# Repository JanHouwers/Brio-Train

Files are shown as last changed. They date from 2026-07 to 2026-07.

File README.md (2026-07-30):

# Brio-Train — a remote-controlled BRIO-compatible locomotive

A 3D-printed, battery-powered locomotive for BRIO-style wooden track, with a matching handheld
remote. Both units use a **Seeed XIAO ESP32-C5** and talk over **ESP-NOW**; both charge over USB-C.

| | Locomotive | Remote |
|---|---|---|
| Controller | XIAO ESP32-C5 | XIAO ESP32-C5 |
| Power | 2S, 2× XTAR 14500 protected (6.0–8.4 V) | 1S, XTAR 26650 protected |
| Charging | IP2326 2S USB-C balance charger | TP4056 USB-C |
| Drive | N20 6 V 150 rpm → DRV8833, O-ring belt to one rear wheel | — |
| Controls | headlight, horn | KY-023 joystick (throttle + horn), link LED, battery LED |
| Link | ESP-NOW broadcast, channel 1, 2.4 GHz, MAGIC-filtered | ESP-NOW, 25 Hz, telemetry ack back |

Speed is roughly 16 cm/s; the firmware caps the PWM duty at 75 % so the 6 V N20 survives the 8.4 V
pack.

> **Build status:** the remote is wired and working. The locomotive is documented and its firmware
> runs on the bare board, but **it is not wired up yet**. The radio link has been demonstrated in
> both directions. See [`docs/status.md`](docs/status.md) for exactly what has and has not been
> tested.

## Repository layout

```
firmware/
  loco/     PlatformIO project — receiver / drive controller  (rev D)
  remote/   PlatformIO project — handheld transmitter          (rev F)
hardware/
  wiring-loco.svg / .png     wiring diagram, locomotive (SVG is the source)
  wiring-remote.svg / .png   wiring diagram, remote
cad/
  Train.3dm / .stp             locomotive body + chassis
  Remote.3dm / .stp            remote enclosure
  pulley-and-wheels.3dm / .stp drive pulley and wheels
stl/
  9 print-ready meshes, generated from the STEP files above
docs/
  bom.md            bill of materials
  wiring-loco.md    wire list L1–L29, measurements, DRV8833 module notes
  wiring-remote.md  wire list W1–W19, battery sensing, deep sleep
  assembly.md       print settings and mechanical assembly
  status.md         build log, what is tested, what is next
```

Only the current revisions are in this repository (loco rev D, remote rev F). Earlier revisions
targeted the XIAO ESP32-S3, which has a different pinout; do not mix them.

## Quick start

### 1. Flash the firmware

Both projects are PlatformIO projects. The ESP32-C5 needs arduino-esp32 core ≥ 3.3, which is not in
the official `espressif32` platform, so both `platformio.ini` files point at the
[pioarduino](https://github.com/pioarduino/platform-espressif32) fork (release 55.03.311). That
requires **PlatformIO Core ≥ 6.1.19**.

```bash
cd firmware/remote        # or firmware/loco
pio run -t upload
pio device monitor -b 115200
```

On Windows, set `PYTHONIOENCODING=utf-8` (or run `chcp 65001`) first — otherwise the upload aborts
halfway with a `UnicodeEncodeError` when esptool draws its progress bar.

No pairing is needed: both ends find each other through a shared `MAGIC` key on Wi-Fi channel 1.

**Flash and bench-test before you solder anything.** With a bare XIAO you can already verify the
radio link, the headlight and the horn.

### 2. Print the parts

Nine parts, ready to slice, in [`stl/`](stl/) — see [`stl/README.md`](stl/README.md) for the part
list and quantities, and [`docs/assembly.md`](docs/assembly.md) for orientation, supports and print
settings. PETG, 0.4 nozzle, 0.2 mm layers, 3 perimeters, 20 % infill.

The STLs are derived from the STEP files in [`cad/`](cad/); the CAD is the source of truth.

### 3. Order the parts

See [`docs/bom.md`](docs/bom.md). Two things in there are easy to get wrong:

- the buck converter must be an **adjustable** MP1584EN set to **5.0 V** (not a fixed Mini-560);
- the master switch in the locomotive carries the full motor current — use one rated **≥ 2 A**, plus
  a 2 A fuse.

### 4. Wire it up

Follow [`docs/wiring-loco.md`](docs/wiring-loco.md) and [`docs/wiring-remote.md`](docs/wiring-remote.md)
alongside the diagrams in [`hardware/`](hardware/). Both documents give the assembly order, the
verification measurements to take before fitting the cells, and the expected values after switching
on. The locomotive has **two separate grounds** (PWR and SIG) joined only through the buck — that is
not a detail, it is what keeps 1 A of motor current out of the ADC reference.

## How it behaves

- Joystick forward/back = speed, press = horn.
- **Neutral lockout**: after power-up or signal loss the locomotive only drives once the stick has
  been at centre.
- **Failsafe**: the locomotive stops 400 ms after signal loss.
- Green LED on the remote = link alive (telemetry ack received from the locomotive).
- Red LED solid = remote cell low; blinking = **locomotive** pack low (the locomotive also stops and
  blinks its headlight).
- The remote deep-sleeps after 5 minutes idle; press the joystick to wake it. It does not sleep while
  a USB host was present at boot, so the COM port stays available while developing.
- Both units print a calibration line over USB every 2 seconds, so the battery measurement can be
  trimmed against a multimeter instead of guessed (`VDIV_CAL`).

## Known limitations

- The throttle scaling is symmetric while the joystick is not, so forward and reverse are not
  perfectly matched. Fix is described in [`docs/wiring-remote.md`](docs/wiring-remote.md).
- There is no breakaway (`MIN_DUTY`) threshold yet, so the first part of the stick travel produces
  whine rather than movement.
- `MAX_DUTY` is a percentage of pack voltage, so speed drops as the pack drains. The locomotive
  already measures the pack, so this can be compensated in firmware.
- Motor speed cannot be measured with the current hardware — no encoder, and the only header ADC pin
  is taken by the pack voltage divider.
- nSLEEP and nFAULT of the DRV8833 are deliberately not wired; protection is entirely in software.

See [`docs/status.md`](docs/status.md) for the full analysis and what is planned next.

## Safety

Lithium-ion cells, a balance charger and a motor driver in a toy: build it carefully.

- The 2S charger must be an IP2326-type **balance** board wired B−/BM/B+. Never charge this pack
  through a plain 1S board.
- Check cell polarity before fitting. The printed bays accept a reversed cell; the protection inside
  the cell will not save the charger.
- The low-battery auto-stop is the primary over-discharge guard — do not disable it.
- Master switch off while charging and while flashing, on both units.
- Body screws on before it goes near a child; charging only under supervision.

## Licence

Firmware is MIT; hardware, CAD and documentation are CERN-OHL-S v2. See [`LICENSE`](LICENSE).

BRIO is a trademark of BRIO AB. This is an independent hobby project, not affiliated with or endorsed
by BRIO.

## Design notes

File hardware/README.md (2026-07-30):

# Wiring diagrams

| Unit | Source | Rendered |
|---|---|---|
| Locomotive, rev D | `wiring-loco.svg` | `wiring-loco.png` (3580 × 2580) |
| Remote, rev F | `wiring-remote.svg` | `wiring-remote.png` (2800 × 2040) |

**The SVG is the source.** The PNGs are rendered from it at 2× scale for viewing and printing; if you
change a diagram, edit the SVG and re-render.

Read them alongside the wire lists — [`../docs/wiring-loco.md`](../docs/wiring-loco.md) and
[`../docs/wiring-remote.md`](../docs/wiring-remote.md) — which carry the wire numbers, gauges,
assembly order and verification measurements.

Conventions used in both diagrams: a filled dot is a connection, a crossing without a dot is not.
In the locomotive diagram a thick line carries motor current (AWG20). Wire numbers (L1…L31, W1…W19)
match the wire lists exactly.

## Re-rendering

**This is automated.** Push a changed SVG and the
[`Render wiring diagrams`](../.github/workflows/render-diagrams.yml) workflow re-renders both PNGs
and commits them back. Pull requests do not get a commit; there the workflow fails if the committed
PNGs no longer match their SVG, so a stale image cannot be merged.

To do it by hand — after editing an SVG locally, or to check the result before pushing:

```powershell
pwsh tools/render-diagrams.ps1
# or, with Windows PowerShell:
powershell -ExecutionPolicy Bypass -File tools\render-diagrams.ps1
```

The script finds Chrome or Edge, reads each SVG's own `width`/`height`, renders at 2× that size and
verifies the resulting image really has those dimensions.

**Render on Windows.** The diagrams specify `Segoe UI, Arial, sans-serif` and were laid out against
Segoe UI metrics; a Linux renderer falls back to a different font and text starts to overflow its
boxes. That is also why the workflow runs on `windows-latest`.

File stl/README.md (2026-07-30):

# Print-ready STLs

Meshed from the STEP files in [`../cad/`](../cad/), which are the Rhino exports of the current
design. Every part is translated to sit on **Z = 0** and centred in X/Y; the orientation is the one
from the CAD.

| File | Qty | Size (mm) | Facets | From |
|---|-----|---|---|---|
| `loco-chassis.stl` | 1 | 130.0 × 34.8 × 35.0 | 4,450 | `Train.stp` → `chassis` |
| `loco-boiler.stl` | 1 | 68.0 × 40.1 × 52.0 | 19,266 | `Train.stp` → `Body` |
| `loco-cab.stl` | 1 | 42.0 × 43.0 × 46.0 | 7,962 | `Train.stp` → `Body001` |
| `loco-front.stl` | 1 | 8.9 × 40.1 × 45.0 | 6,386 | `Train.stp` → `Voorkant` |
| `loco-wheel-plain.stl` | 3 | Ø20.8 × 5.0 | 3,292 | `pulley-and-wheels.stp` → `#1305` |
| `loco-wheel-driven.stl` | 1 | Ø20.0 × 7.6 | 2,584 | `pulley-and-wheels.stp` → `Pulley001` |
| `loco-pulley.stl` | 1 | Ø11.0 × 4.0 | 1,120 | `pulley-and-wheels.stp` → `Pulley` |
| `remote-bottom.stl` | 1 | 170.0 × 56.0 × 22.0 | 6,410 | `Remote.stp` → `Remote bottom` |
| `remote-top.stl` | 1 | 170.0 × 56.0 × 29.2 | 25,984 | `Remote.stp` → `Remote top` |

The locomotive body is split into four printable pieces — chassis, front, boiler and cab — instead of
the single body of earlier revisions. **The split exists to keep support material to a minimum:**
each piece prints in an orientation that needs little or none. The three top pieces (front, boiler,
cab) are **glued together with superglue (cyanoacrylate)**; only the assembled body is screwed to the
chassis.

**Which wheel is which:** `loco-wheel-driven` is the thicker one (7.6 mm, `Pulley001` in the CAD) and
carries the belt hub — it goes on the rear right. `loco-wheel-plain` (5.0 mm) is the running wheel:
twice at the front and once at the rear left.

## Mesh quality

Tessellated at 0.03 mm linear deviation and 0.2 rad angular deviation. All nine meshes are closed
(watertight), have no self-intersections, and their volumes are within 0.32 % of the CAD solids.

## Regenerating

The STLs are derived files — the CAD in [`../cad/`](../cad/) is the source. Export from Rhino, or
regenerate from the STEP files with FreeCAD:

```python
import Import, Mesh, MeshPart
from FreeCAD import Vector
doc = FreeCAD.newDocument("exp")
Import.insert("cad/Train.stp", doc.Name)
obj = doc.getObjectsByLabel("chassis")[0]
sh = obj.Shape.copy()
bb = sh.BoundBox
sh.translate(Vector(-(bb.XMin + bb.XMax) / 2, -(bb.YMin + bb.YMax) / 2, -bb.ZMin))
m = doc.addObject("Mesh::Feature", "m")
m.Mesh = MeshPart.meshFromShape(Shape=sh, LinearDeflection=0.03,
                                AngularDeflection=0.2, Relative=False)
Mesh.export([m], "stl/loco-chassis.stl")
```

See [`../docs/assembly.md`](../docs/assembly.md) for print settings, orientation and supports.

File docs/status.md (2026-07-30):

# Project status — 2026-07-28

Both units run on the **Seeed XIAO ESP32-C5** and were both flashed with the current firmware on
28 July. The remote is wired; the **locomotive is not yet connected** — all documents are ready, but
no wire has been laid. The loco firmware has been seen running on the bare XIAO (the first part of
step 0 below; link LED, buzzer and the PWM test are still open).

The **radio link was demonstrated on 28 July**, in both directions, with both units on USB — see the
link test below.

## Build status — verified 2026-07-28

Both projects were built on the same platform used to flash the remote (`pioarduino 55.03.311`,
arduino-esp32 core 3.3.11, IDF 5.5.5, esptool 5.3.1):

| Project | Result | RAM | Flash |
|---|---|-----|---|
| `firmware/loco` | SUCCESS, 0 warnings | 14.8 % (48,552 / 327,680) | 31.1 % (1,040,695 / 3,342,336) |
| `firmware/remote` | SUCCESS, 0 warnings | 14.8 % (48,592 / 327,680) | 31.1 % (1,037,887 / 3,342,336) |

Nothing comes out with `-Wall -Wextra` either. The two things that break fastest on a C5 —
`esp_wifi_set_band_mode()` and the new `esp_now_register_recv_cb` signature with
`esp_now_recv_info_t` — both compile fine.

## Both units flashed on 28 July — which is which

The two XIAOs can be told apart by their chip MAC. Useful, because they are identical and PlatformIO
will happily flash whichever one you point it at:

| Unit | Chip MAC | Port on 28 July |
|---|---|---|
| **loco** | `10:BD:A3:CF:A7:2C` | COM4 |
| **remote** | `10:BD:A3:CF:09:54` | COM3 |

Check with `pio device list` before every upload which MAC is attached — the port numbers change.
Second check via `device monitor`: the loco prints `pack ... mV ... | link ... armed ... fault ...`,
the remote prints `cell ... mV (... ratio 2.000 ...) | loco ... mV`.

The remote was flashed with `WiFi.setSleep(false)` included; after the reset it runs and reads the
cell at 4023 mV (pin 2011 mV, ratio 2.000). The `loco 8000 mV` in that line is still the startup
value of `locoPackMv` — no locomotive was powered, so no ack had arrived yet.

## Link test loco ↔ remote — passed on 28 July

Both XIAOs on USB simultaneously (COM3 + COM4), both monitors read side by side:

```
REMOTE  cell 4025 mV (...) | loco 7214 mV     LOCO  pack 7285 mV (D0 2428 mV) | link 1 armed 1 fault 0
REMOTE  cell 4025 mV (...) | loco 6735 mV     LOCO  pack 6765 mV (D0 2255 mV) | link 1 armed 1 fault 0
REMOTE  cell 4023 mV (...) | loco 2692 mV     LOCO  pack 3613 mV (D0 1204 mV) | link 1 armed 1 fault 0
REMOTE  cell 4024 mV (...) | loco    0 mV     LOCO  pack   42 mV (D0   14 mV) | link 1 armed 1 fault 0
```

What this proves:

- **Outbound.** `link 1` on the loco: broadcasts arrive that pass the `MAGIC` filter and the length
  check. So channel 1, 2.4 GHz and the `Packet` struct are correct on both sides.
- **Return path.** The remote no longer shows `loco 8000 mV` (the startup value) but a real value,
  and that value **tracks the wobbling D0 reading of the locomotive** — 7214 against 7285, 6735
  against 6765, and both drop to zero. That is not a coincidence: the unicast ack to
  `info->src_addr`, adding the peer, and the `Ack` struct all work. That also means the green link
  LED is lit (`lastAckMs` < 500 ms).
- **`armed 1`.** The locomotive saw `targetSpeed == 0` and released the neutral lockout. Which
  immediately means the joystick zero point at that boot **fell inside the deadband** — the scenario
  in point 1 below (skewed `joyCenter` → never `armed`) did not occur. Note: that is one observation
  at one boot, not a guarantee.

That the pack voltage reads nonsense and wobbles between 0 and 7.3 V is expected: D0 on the
locomotive is still floating. `lowBatt` flips back and forth as a result, and on the remote the red
LED blinks as soon as the reported value drops below 6400 mV.

**Not tested** (impossible without wiring or without extra diagnostics): horn, headlight, and whether
a stick deflection actually produces the right speed — the locomotive does not print `targetSpeed` /
`currentSpeed` anywhere yet.

## Bench test, locomotive — done on 28 July

The bare XIAO was flashed on **COM4** (chip MAC `10:bd:a3:cf:a7:2c`), all four segments with
`Hash of data verified`. The serial monitor shows the calibration line:

```
pack 2643 mV (D0 881 mV, ratio 3.000 x cal 1.000) | link 0 armed 0 fault 0
pack 0 mV (D0 0 mV, ...)      <- wobbles between 0 and 4355 mV
```

That is exactly the expected picture: **D0 is floating and drifts**, so `lowBatt` trips after three
readings and the headlight should blink at 300 ms. `link 0 armed 0` is right too — no remote was
switched on.

That drifting reading is itself the proof it was **the loco XIAO** and not accidentally the remote:
on the wired remote, D0 carries the VRy tap of the joystick, which would give a stable ~1.65 V (pack
would then read a constant ~4950 mV) instead of jumping between 0 and 4355 mV.

**Still to do** from step 0: switch the remote on to check the link LED, press the joystick for the
buzzer, and tie D0 to 3V3 temporarily to release the PWM on D4/D5.

## Two toolchain pitfalls — both solved, but worth remembering

1. **`UnicodeEncodeError` while uploading.** `pio run -t upload` dies with a `charmap` error as soon
   as esptool draws its progress bar: the console is on cp1252 and cannot render those characters.
   The flash is then half finished. Fix: `PYTHONIOENCODING=utf-8` in the environment, or `chcp 65001`
   before the command. This is the same cause as the message *"Firmware metrics can not be shown. Set
   the terminal codepage to utf-8"*.
2. **`build_dir` belongs in `[platformio]`, not in `[env:...]`.** Under the env section PlatformIO
   ignores it without complaining and builds inside the synced folder anyway — and then the build
   fails with `FileNotFoundError` on `.pio`, because the sync client has the directory open. Both
   files are correct now; the warning is included as a comment.

## Locomotive — build order

**Firmware first, wiring second.** Flash the bare XIAO C5 over USB before soldering anything: that
way you test the radio link, the headlight (D9) and the horn (D10) without a single solder joint.

0. **Bench test on the bare XIAO:** *(flashing + calibration line were done on 28 July, the rest not
   yet)*
   ```
   set PYTHONIOENCODING=utf-8
   pio run -t upload
   pio device monitor -b 115200
   ```
   Use PlatformIO Core ≥ 6.1.19 (the `pio` on PATH may be older; the one in
   `%USERPROFILE%\.platformio\penv\Scripts\` is usually current). Without `PYTHONIOENCODING` the
   upload aborts with a `UnicodeEncodeError` — see the pitfalls above.
   - D0 is floating, so the pack voltage reads nonsense and `lowBatt` trips → **the headlight blinks
     at 300 ms**. That confirms that branch works.
   - Switch the remote on: the **green link LED** must come on. That proves the whole radio chain
     (channel 1, 2.4 GHz, MAGIC, Packet/Ack).
   - Press the joystick → the buzzer on D10 must sound.
   - To see the motor drive: tie **D0 to 3V3 temporarily**. The firmware then reads 3.3 × 3.0 = 9.9 V,
     `lowBatt` clears and the PWM on D4/D5 is released.
1. **Measure the DRV8833 module while disconnected**, before anything else: `EEP↔VCC` and `ULT↔VCC`.
   - open or ±47 kΩ → good, carry on
   - near 0 Ω → J1 is closed. **Wick it off first**, otherwise L17 shorts the 3V3 of the XIAO against
     8.4 V as soon as you switch on.
2. **Set the buck to 5.0 V** with a bench supply, before mounting. Adjustable MP1584EN, not a fixed
   Mini-560.
3. **Lay wires L6–L31** (L18–L21 are dropped; that makes 27: L1–L17 + L22–L29 + L30–L31, the
   external USB-C charge socket).
4. **L1–L5** (pack, charger, star point) last, and only then fit the cells.
5. Verification measurements from the wire list — **motor still disconnected**.
6. Reflash, calibrate `VDIV_CAL` against the multimeter on VBAT_SW, and only then connect the motor.
7. Apply throttle with the locomotive on blocks. Free-running N20 = 60–100 mA, stalled 0.7–1 A.

## Protocol check loco ↔ remote — matches

Verified on 28 July, both sides side by side:

| Item | Loco | Remote |
|---|---|---|
| `Packet` | 8 B, `packed`: magic/speed/flags/seq | identical |
| `Ack` | 7 B, `packed`: magic/packMv/seq | identical |
| `MAGIC` | `0xB210C0DE` | identical |
| Channel | 1 | 1 |
| Band | `WIFI_BAND_MODE_2G_ONLY` | `WIFI_BAND_MODE_2G_ONLY` |
| Role | receives broadcast, answers unicast to `info->src_addr` | sends broadcast, receives ack |

## What is deliberately not connected

nSLEEP and nFAULT are **not wired** — the goal is to avoid soldering on the module.

- **EEP** is tied to the 3V3 pin of the XIAO via **L17**. So the driver is always awake (~2 mA idle
  as long as SW1 is on). J1 stays open: VCC is 8.4 V here and the logic pins take 7 V maximum.
- **ULT** stays floating. No detection of short circuit or overheating. That is manageable: the OCP
  of the DRV8833 sits at 2–3.3 A and a stalled N20 only reaches ~1 A, so nFAULT would not have seen
  that anyway.
- **XIAO D1 and D8 stay free.** In firmware: `HAVE_NSLEEP 0` and `HAVE_NFAULT 0`.
- Protection now comes entirely from software: neutral lockout, link timeout, low-battery threshold
  (6600/6900 mV) and `if (!mayDrive) tgt = 0;`. That last line **must stay** — with EEP fixed high,
  `driverAwake` is always true and the ramp counter would otherwise keep running.

## Two things that easily go wrong

- **Two grounds.** PWR = star point at PACK− (pack−, buck IN−, DRV8833 GND, C3/C4). SIG = the GND pin
  of the XIAO (divider, LED1, BZ1). The only connection runs through the buck (L8 ↔ L10). **Do not
  add a second wire between them** — otherwise 1 A of motor current runs through your measurement
  ground.
- **SW1.** The SS12D00 from the original BOM is rated 0.3–0.5 A and has to carry 0.7–1 A here plus
  the inrush of C3. Use a switch rated ≥ 2 A or a P-MOSFET load switch, and a 2 A fuse/PTC directly
  after SW1.

## Next up: diagnostics + joystick ↔ motor speed

None of this is implemented yet — this is the analysis, not the code.

### Where things stand

The radio link is proven (see the link test above), so you can treat it as a given while calibrating.
What is missing is **visibility into the control chain itself**: neither unit prints what the joystick
produces or what the locomotive does with it. As long as that is the case, a locomotive that does not
move is indistinguishable from a locomotive that is being handed a speed of 0. So print first, drive
second.

### The chain stick → speed, and where it can bind

Five links, from the ADC in the remote to the worm gear in the locomotive:

1. **`joyCenter` comes from 32 readings at every boot** (`remote/src/main.cpp`) — and the stick has
   to be released at that moment. If it is not, the zero point is skewed. If it is off by more than
   the deadband, `speed` never becomes 0, the locomotive is **never released** into `armed` and it
   does nothing at all. That looks like a broken radio link while the link is perfectly fine.
   `joyCenter` is not printed anywhere, so right now this is invisible. **First thing to build in.**
2. **The scaling is symmetric, the joystick is not.** `readThrottle()` divides by a fixed 2048,
   regardless of where the centre actually sits. With `joyCenter` = 1900, reverse only reaches 93 %
   and the top 5 % of the forward travel is dead (the constrain clips it). Already listed under
   "still open"; scaling per direction against the real distance to 0 respectively 4095 fixes it.
3. **Deadband ±80 of 1000** = 8 % of the travel. Fine as a rest zone, but it stacks on top of point 4.
4. **There is no breakaway threshold.** A geared N20 only starts moving at roughly 15–25 % duty. The
   region between the deadband and that point therefore produces only current and whine, no movement
   — it feels like a dead zone of a quarter turn. A `MIN_DUTY` where the scale runs from the
   breakaway point to `MAX_DUTY` instead of from 0 makes the stick usable over its whole travel. That
   threshold has to be **measured**, not guessed: on blocks, raise the duty slowly until the wheel
   just turns.
5. **`MAX_DUTY` is a percentage of the pack voltage, not of a fixed motor voltage.** 75 % of 8.4 V is
   6.3 V, but 75 % of 6.6 V (just above the low-battery threshold) is 4.95 V. So the speed at the
   same stick position drops ~21 % as the pack drains. The locomotive **already measures `packMv`**,
   so compensating costs no extra wire: derive the duty from a desired motor voltage. Watch the upper
   limit — never above 80 % duty, and with a full pack never above the 6.3 V the N20 is set up for.

### Hard limitation: speed cannot be measured with the current hardware

There is **no encoder on the N20**, and back-EMF measurement is not possible here: of the header pins
only **D0 (GPIO1) is on ADC1**, and it is taken by the pack voltage divider. The C5 has no ADC2. So
"speed" is by definition a derivative of duty and motor voltage, supplemented by what you determine
on blocks by eye or with a tacho app. Measuring it properly is a **hardware change** — an optical or
hall sensor on a free GPIO (D1 and D8 are free, see `HAVE_NSLEEP 0` / `HAVE_NFAULT 0`) — and then the
pin assignment has to go past the wire list again.

### What could be built in

**Remote:**
- Extend the calibration line with the raw ADC value, `joyCenter`, and `v` after scaling. Without
  those three, calibrating is guesswork.
- Calibration mode: hold the joystick pressed at boot → measure the end stops and centre and write
  them to NVS (`Preferences`), so the zero point no longer depends on whether the stick happened to
  be released at boot.
- Scale per direction (point 2).

**Locomotive:**
- Extend the calibration line with `targetSpeed`, `currentSpeed` and the actual duty, plus
  `armed`/`mayDrive`/`lowBatt`/`faultShutdown` as separate flags. Right now you only see
  `link armed fault`.
- `MIN_DUTY` and voltage compensation (points 4 and 5), only after the breakaway point is measured.

**Telemetry — mind the trap:** extending the `Ack` with speed and status flags is the clean way to
see on the remote what the locomotive is doing, but **both sides filter on `len != sizeof(...)`**. If
you change the struct, loco and remote must be reflashed in the same pass, otherwise the link goes
silent without any message — the packets are simply discarded.

## Still open, apart from the locomotive

- **Headlight LED, 47 Ω.** With a white LED (Vf ≈ 3.0–3.2 V) only 0.1–0.3 V is left across the
  resistor; the LED itself becomes the limiter and the brightness is not well defined. Put a red LED
  in there by mistake and you draw ~30 mA from the GPIO. More robust: drive the headlight from the
  5 V rail through an NPN (BC547, 1 kΩ base resistor from D9) with **180 Ω** in series.
- **Green LED on the remote, 470 Ω.** 470 Ω is right for the red LED (Vf ≈ 1.9 V → 3 mA), but a
  bright green InGaN LED has Vf ≈ 3.0–3.2 V and barely lights up. Use a green one with Vf ≤ 2.2 V, or
  220 Ω.
- `readThrottle()` in the remote firmware scales both directions equally; with a joystick whose
  centre is not exactly at half, forward and reverse are not symmetric. The fix (scale per direction)
  has been discussed but is not in the code yet.
- **The locomotive enclosure has not been test-fitted against the wired electronics.** The CAD in
  [`../cad/`](../cad/) is the current source and print-ready meshes are in [`../stl/`](../stl/). The
  body is split into a chassis plus three top pieces (front, boiler, cab) so each prints with little
  or no support; the three top pieces are glued together with superglue. The e-shelf tray from the
  earlier design is gone — the boards mount in the chassis and the space inside the boiler and cab
  takes the rest, so every board has to be insulated (Kapton) with no exposed conductors before it
  goes in. Charging runs through a separate 2-wire USB-C socket (L30/L31) instead of the charger
  board's own port.

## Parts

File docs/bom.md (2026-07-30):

# Bill of Materials

Current hardware revision: **loco rev D / remote rev F**, both on the Seeed **XIAO ESP32-C5**.
Component designators (R1, C3, SW1, …) match [`wiring-loco.md`](wiring-loco.md) and
[`wiring-remote.md`](wiring-remote.md) and the two wiring diagrams in [`../hardware/`](../hardware/).

> Earlier revisions of this project used the XIAO ESP32-S3. The C5 has a different pinout and only
> one ADC unit; do not mix the two. See the wire lists for the details.

## Controllers and cells

| # | Part | Notes |
|---|---|---|
| 2 | Seeed XIAO ESP32-C5 | 1× loco, 1× remote (21 × 17.5 mm). Requires arduino-esp32 core ≥ 3.3 |
| 2 | XTAR 14500, 3.7 V 1200 mAh, protected | Ø14.3 × 50.5 mm — loco pack, 2S (6.0–8.4 V) |
| 1 | XTAR 26650, 3.6 V 6000 mAh, protected, button top | Ø26.5 × 69.3 mm — remote, 1S |

Protected 14500 cells are 50.5 mm — 0.5 mm longer than an AA. The printed bay accounts for this; an
off-the-shelf AA holder may be too tight.

## Locomotive

| # | Ref | Part | Spec / example | Why |
|---|-----|---|---|-----|
| 1 | M1 | N20 gearmotor | 6 V, ~150 rpm, metal gears, 3 mm D-shaft, body 12 × 10 × 24 mm | Drive. 2 A protected cells handle N20 stall (~0.7–1 A) fine |
| 1 | U4 | DRV8833 module | Dual H-bridge breakout, ~18 × 15 mm, Vmax 10.8 V | Motor driver, runs directly off the 2S pack. One channel used |
| 1 | U1 | 2S USB-C Li-ion charge module | IP2326-based, "2S 8.4 V USB-C balance charging board" | Built-in USB-C charging including balancing of both cells |
| 1 | J2 | USB-C female connector, 2-wire, with snap-groove buckle | 3 A "fast charge" type, e.g. Greluma 5-pack (amazon.nl) | Charge socket. Its two leads solder to the charge input of U1, so the USB-C port of the charger board itself does not have to reach a wall |
| 1 | U2 | Buck converter, **adjustable** | MP1584EN set to **5.0 V**, ≥1 A | 2S pack → 5V pin of the XIAO. **Not** a fixed Mini-560 — see below |
| 4 | — | AA battery contacts | 2× spring (negative) + 2× button plate (positive), Keystone 5201/5203 style or from a scrap AA holder | Press into the printed battery bay |
| 1 | SW1 | Slide switch, **≥ 2 A** | 1P2T, 3–4 mm travel | Master power. The SS12D00 from earlier revisions is too light — see below |
| 1 | — | Fuse or PTC, 2 A | — | Directly after SW1 |
| 1 | LED1 + R1 | White LED 5 mm + 47 Ω | LED with Vf ≤ 2.9 V | Headlight |
| 1 | BZ1 + R2 | Passive piezo buzzer + 100 Ω | 12 mm disc or 9 mm passive buzzer | Horn |
| 2 | — | O-ring | 18 × 2 mm NBR | 1× tyre on the driven wheel, 1× drive belt motor→wheel |
| 1 | — | Steel rod | Ø3 × 32 mm | Front axle (press-fit wheels, spins in the chassis) |
| 2 | — | M3 × 12 screw + washer | — | Rear stub axles; both rear wheels free-spin, the right one is belt-driven |
| 2 | — | Neodymium disc magnet | Ø10 × 3 mm | Couplers front and rear. Check polarity against a Brio wagon before gluing |
| 1 | R3 | Resistor 200 kΩ | 1 % | Pack voltage divider, top leg |
| 1 | R4 | Resistor 100 kΩ | 1 % | Pack voltage divider, bottom leg (ratio 3.0 → D0) |
| 1 | C1 | 100 nF ceramic, X7R | — | Across the divider tap to SIG ground. The divider is 67 kΩ source impedance; the SAR ADC wants < 10 kΩ |
| 1 | C3 | 100 µF low-ESR electrolytic, ≥ 16 V | — | HF decoupling of the H-bridge, loop < 2 cm |
| 1 | C4 | 100 nF ceramic | — | In parallel with C3 |
| 1 | C5 | 10 nF ceramic | — | Across the motor terminals. Do not go larger: 100 nF burns 0.14 W at 20 kHz PWM |
| — | — | Wire | AWG20 (power/motor), AWG22, AWG24, AWG26 (signals) | See the wire list for which gauge goes where |
| — | — | Heat-shrink | — | — |
| — | — | Kapton (polyimide) tape | 10–20 mm wide | Insulate every board before fitting. Everything ends up packed together inside the chassis and body |

## Remote

| # | Ref | Part | Spec / example | Why |
|---|-----|---|---|-----|
| 1 | U1 | TP4056 USB-C charge module | With protection (DW01+FS8205), 1 A | Built-in USB-C charging of the 26650 (~7 h full charge) |
| 1 | J1 | Joystick module | KY-023 dual axis with push switch, 34 × 26 mm | Throttle (Y axis) fwd/rev, push = horn |
| 1 | SW1 | Slide switch | SS12D00 (fine here — no motor current) | Master power |
| 1 | LED1 + R1 | Green LED 3 mm + 470 Ω | **Vf ≤ 2.2 V**, otherwise use R1 = 220 Ω | Link status |
| 1 | LED2 + R2 | Red LED 3 mm + 470 Ω | — | Low battery |
| 1 | R5 | Resistor 100 kΩ | — | External pull-up on D1 (JOY_SW). The internal pull-up disappears in deep sleep |
| 1 | C2 | 100 µF low-ESR electrolytic (≥ 6.3 V) | — | ESP-NOW draws 250–350 mA peaks; without it a nearly empty cell browns the XIAO out |
| 1 | C3 | 100 nF ceramic | — | In parallel with C2 |
| 4 | — | Screws M3 × 12 self-tapping | — | Enclosure halves |
| 2 | — | Battery contacts | 26650/C-cell spring + plate, or solder tabs | Printed battery bay |
| 1 | — | Foam pad 1–2 mm | EVA or double-sided foam tape, ~10 × 10 mm | Between the top-shell pillar and the XIAO RF shield (clamps the board) |

**Dropped compared to the S3 revision:** the external battery divider (R3, R4) and its filter cap
(C1), plus wires W5, W8 and W9. On the C5 the battery sense runs through the divider on the XIAO
itself (GPIO6, enabled by GPIO26), which is not reachable from the header.

## Component notes

- **Do not run the N20 at the full 8.4 V** — the firmware caps PWM duty at 75 % (≈6.3 V effective).
  This is by design; do not raise `MAX_DUTY` above 80.
- **The buck must be adjustable and set to 5.0 V.** The 5V pin of the XIAO feeds the on-board
  SGM40567, which wants to see ~4.5–5.5 V. A fixed Mini-560 no longer reaches 5 V below about 6.5 V
  input, and that is *above* the low-battery stop; the MP1584EN holds 5.0 V down to about 5.4 V in.
- **SW1 in the locomotive carries the full motor current** (0.7–1 A stalled) plus the inrush of C3.
  The SS12D00 is rated 0.3–0.5 A — use a switch rated ≥ 2 A, or have SW1 drive a P-MOSFET load
  switch. Add a 2 A fuse directly after it.
- **The 2S charge module charges through the balance tap (B−, BM, B+).** The midpoint (BM) is the
  junction between the two 14500 cells — it must be wired even though the cells are individually
  protected. Never charge this pack through a plain 1S board.
- **The XIAO in the remote is powered from its BAT pads** (cell voltage). Its own USB port then also
  trickle-charges the cell at ~100 mA if plugged in — harmless, but the TP4056 USB-C port is the
  intended charge port, and with USB plugged in the battery reading always says "full".
- **Headlight LED, 47 Ω:** with a white LED (Vf ≈ 3.0–3.2 V) only 0.1–0.3 V is left across the
  resistor; the LED itself becomes the limiter and brightness is not well defined. Put a red LED
  there by mistake and you draw ~30 mA from the GPIO. More robust: drive the headlight from the 5 V
  rail through an NPN (BC547, 1 kΩ base resistor from D9) with **180 Ω** in series.
- **Green link LED, 470 Ω:** correct for a red LED (Vf ≈ 1.9 V → 3 mA), but a bright green InGaN LED
  has Vf ≈ 3.0–3.2 V and barely lights up. Use a green LED with Vf ≤ 2.2 V, or 220 Ω.

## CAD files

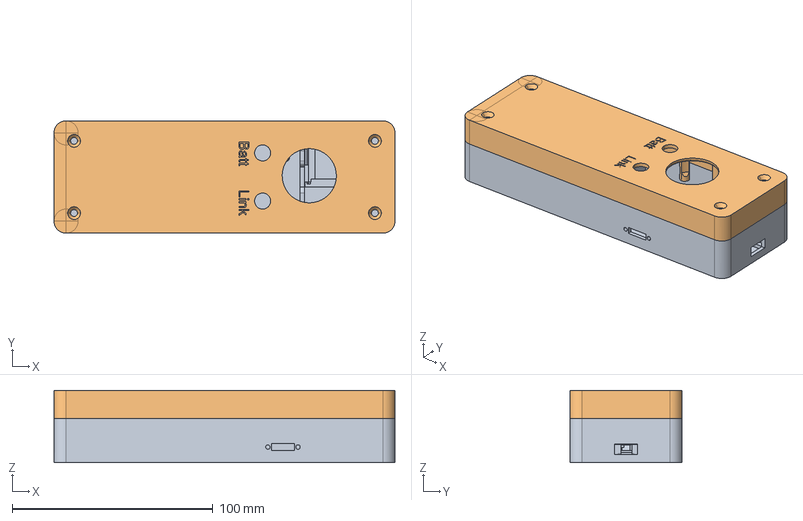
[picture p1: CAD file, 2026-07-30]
cad/Remote.stp
170.0 x 56.0 x 36.0 mm
Remote bottom
Remote top

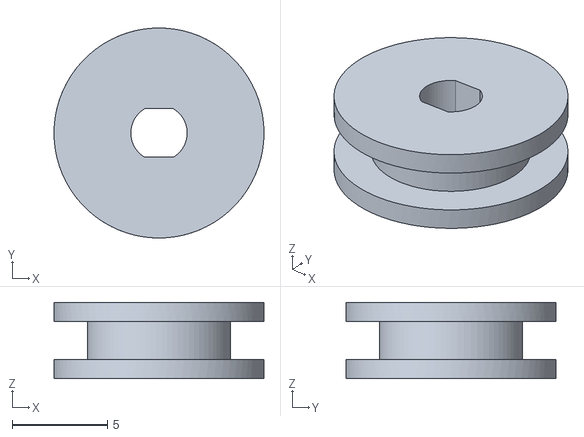
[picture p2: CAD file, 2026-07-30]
stl/loco-pulley.stl
11.0 x 11.0 x 4.00

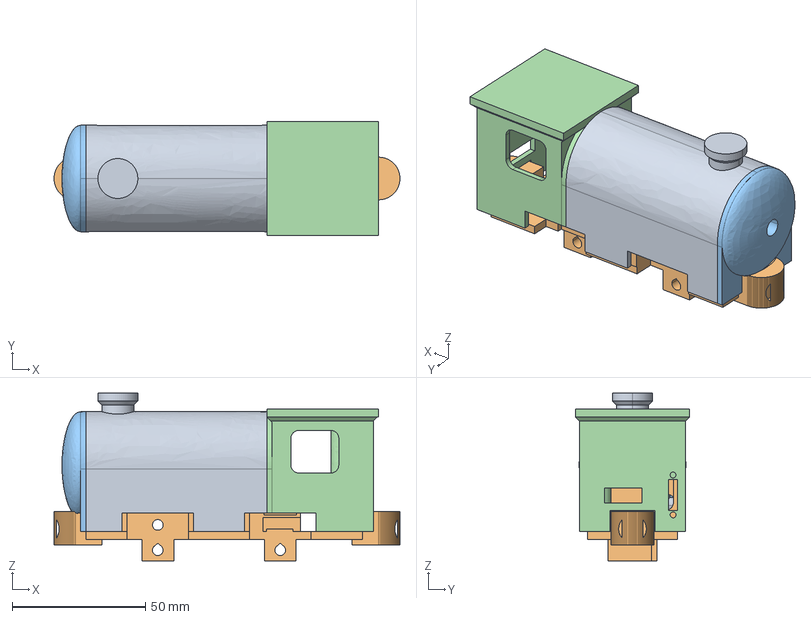
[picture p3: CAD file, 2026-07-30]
cad/Train.stp
130.0 x 43.0 x 63.0 mm
chassis
Voorkant

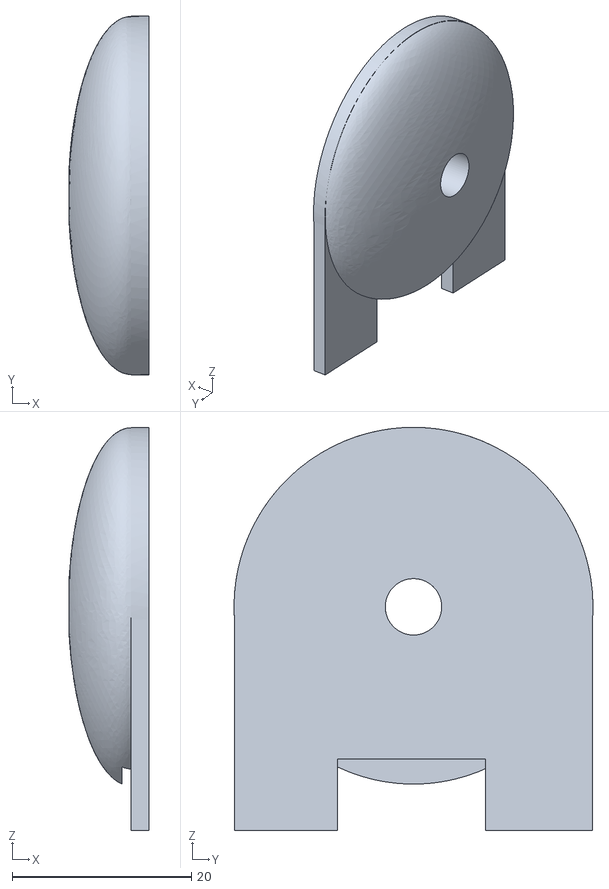
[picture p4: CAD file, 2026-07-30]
stl/loco-front.stl
8.91 x 40.1 x 45.0

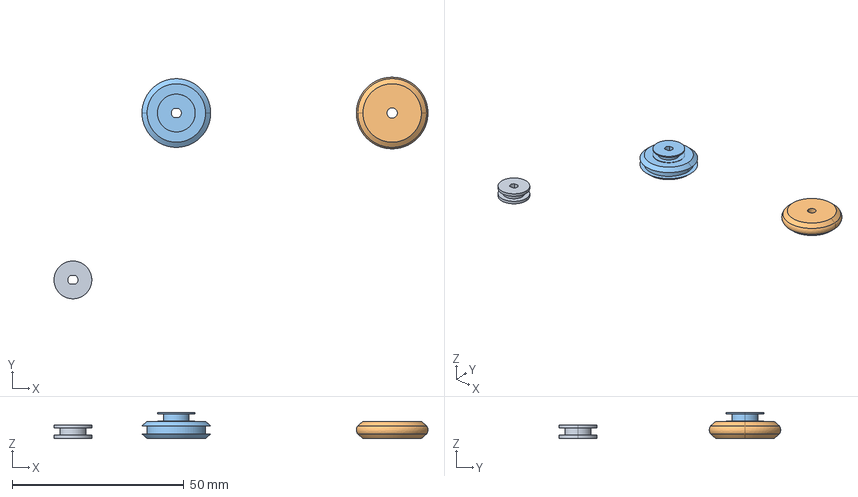
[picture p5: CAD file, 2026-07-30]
cad/pulley-and-wheels.stp
108.8 x 64.5 x 7.57 mm
Pulley x 2

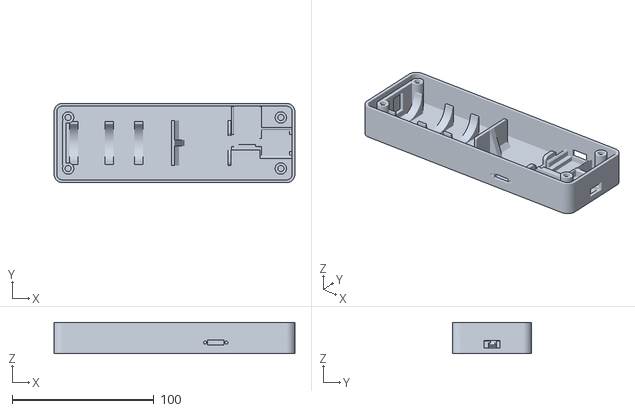
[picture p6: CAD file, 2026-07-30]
stl/remote-bottom.stl
170.0 x 56.0 x 22.0

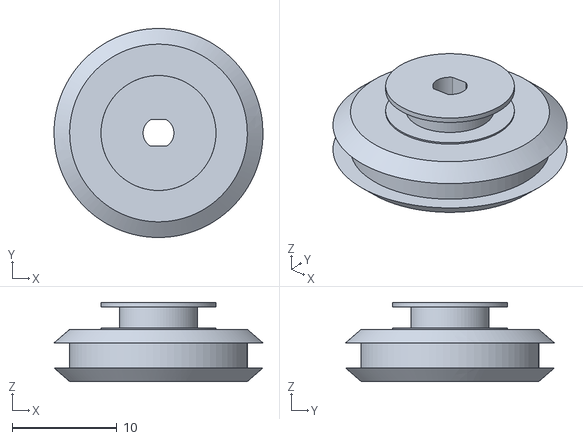
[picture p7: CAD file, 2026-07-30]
stl/loco-wheel-driven.stl
20.0 x 20.0 x 7.57

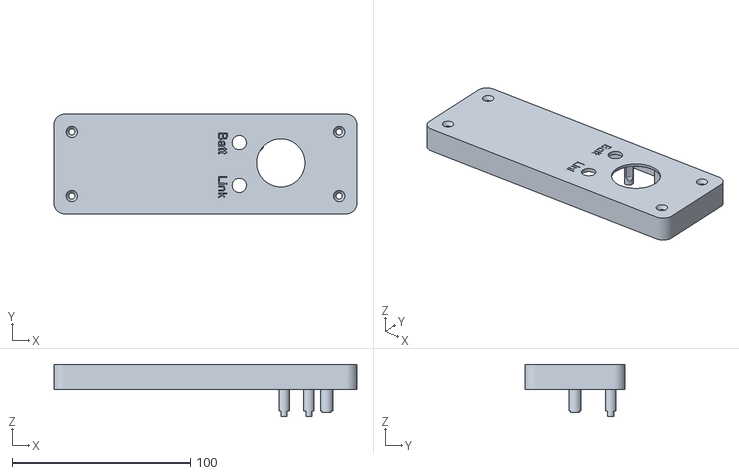
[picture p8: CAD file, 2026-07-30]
stl/remote-top.stl
170.0 x 56.0 x 29.2

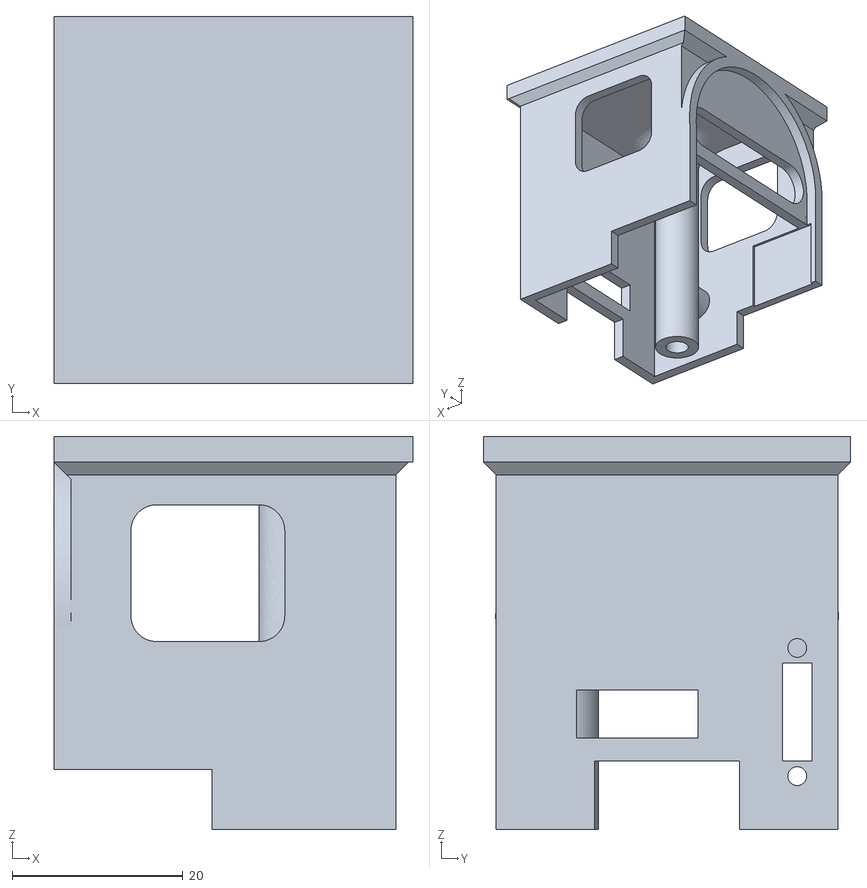
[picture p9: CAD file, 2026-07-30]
stl/loco-cab.stl
42.0 x 43.0 x 46.0

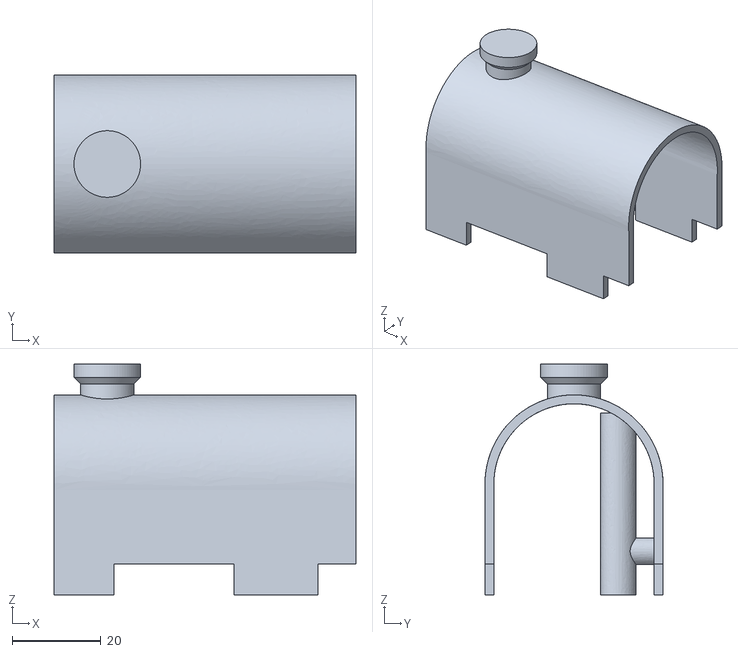
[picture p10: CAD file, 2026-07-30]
stl/loco-boiler.stl
68.0 x 40.1 x 52.0

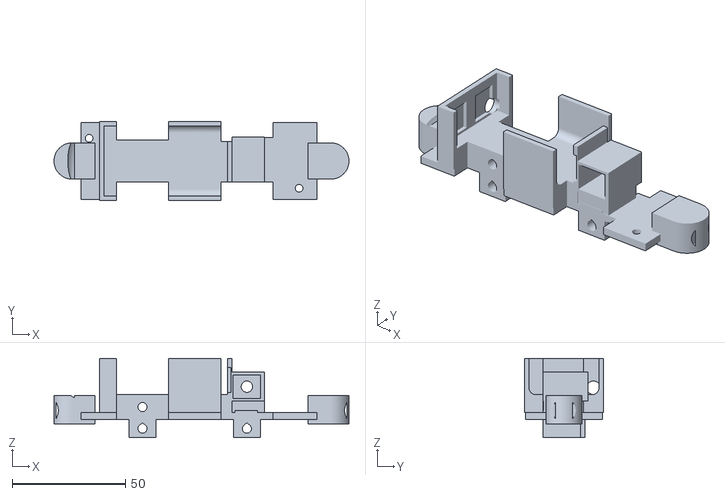
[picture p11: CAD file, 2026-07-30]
stl/loco-chassis.stl
130.0 x 34.8 x 35.0

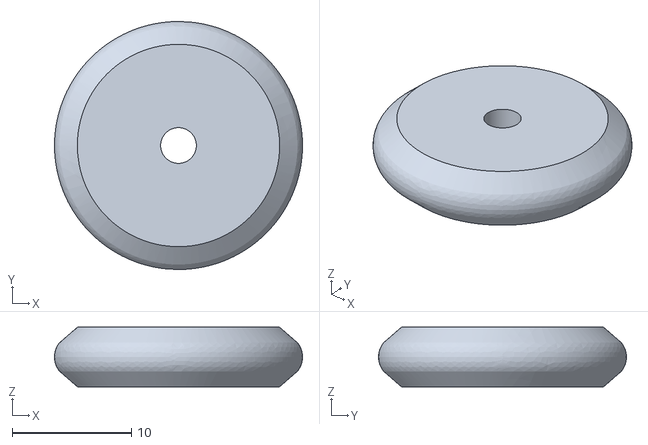
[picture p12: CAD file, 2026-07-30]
stl/loco-wheel-plain.stl
20.8 x 20.8 x 5.00

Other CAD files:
cad/Remote.3dm
cad/Train.3dm
cad/pulley-and-wheels.3dm

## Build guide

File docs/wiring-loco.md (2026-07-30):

# Locomotive — wire list rev D (XIAO ESP32-**C5**)

Goes with [`hardware/wiring-loco.svg`](../hardware/wiring-loco.svg) and
[`firmware/loco/src/main.cpp`](../firmware/loco/src/main.cpp) (PlatformIO). Successor to rev C,
which was for the ESP32-S3. **The wiring itself has not changed** — L1 through L29 still run to the
same components. What changed is **which XIAO label** each signal sits behind, plus the buck
setting.

> Both ends now run on a C5. The remote is documented in [`wiring-remote.md`](wiring-remote.md).

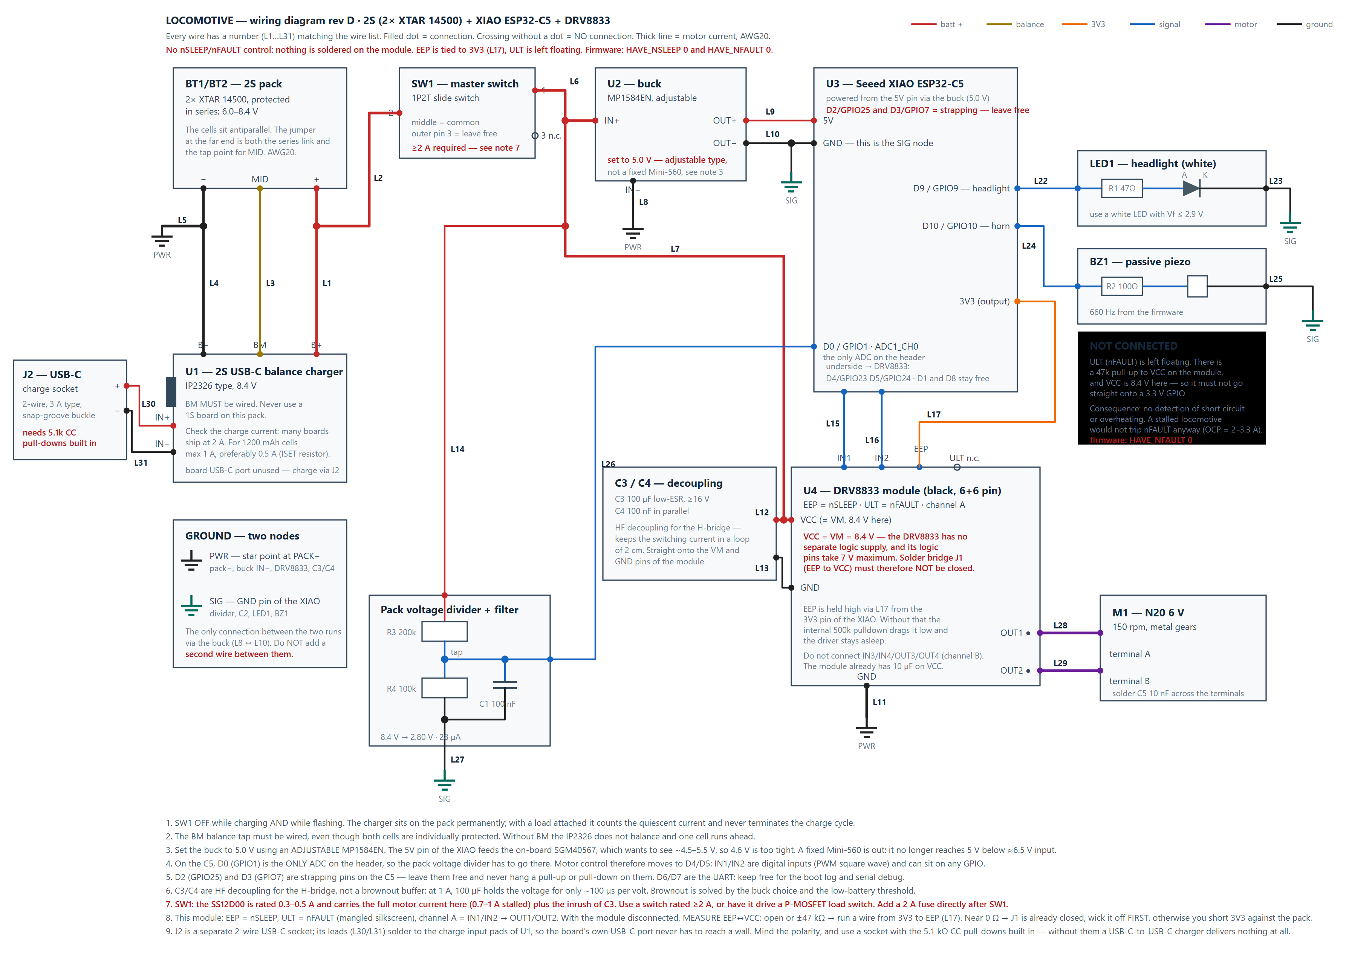
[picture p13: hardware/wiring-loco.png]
Locomotive wiring diagram rev D


## Read this first — four ways to get it wrong

1. **The DRV8833 module used here (black, 6+6 pins) has J1 and a 47k pull-up to VCC.** And on this
   board "VCC" is simply VM, so **8.4 V** — the DRV8833 has no separate logic supply. Connect EEP or
   ULT without removing those and you put 8.4 V on a 3.3 V GPIO. See the separate section
   **"Your module"** below; that is the first thing to check.
2. **The slide switch from the BOM is too light.** The SS12D00 is rated 0.3–0.5 A; the full motor
   current runs through it here (0.7–1 A stalled) plus the inrush of C3. Use ≥2 A, or have SW1 drive
   a P-MOSFET load switch. Plus a 2 A fuse directly after it.
3. **The buck must be set to 5.0 V, and it must be an adjustable type.** See below — this changed
   compared to rev C.
4. **The cell bay is antiparallel.** Nothing stops a reversed cell. Mark the polarity and measure
   PACK+ ≈ 2× MID before switching on for the first time.

## Your module — read this before connecting anything

The silkscreen on this board is mangled English. Decoded:

| Silkscreen | Means | In this design |
|---|---|---|
| `IN1` `IN2` | AIN1, AIN2 | channel A, from D4 and D5 |
| `IN3` `IN4` | BIN1, BIN2 | channel B — **do not connect** |
| `OUT1` `OUT2` | AOUT1, AOUT2 | to the motor |
| `OUT3` `OUT4` | BOUT1, BOUT2 | **do not connect** |
| `EEP` | n**SLEEP** | from D1 |
| `ULT` | nFA**ULT** | to D8 |
| `VCC` | **VM** — there is no separate logic supply | 8.4 V |
| `GND` | ground | PWR star point |
| `J1` | solder bridge next to EEP, silkscreen "en sleep" | connects EEP to VCC |

**That VCC is the same net as VM is the whole problem.** The DRV8833 has one supply pin. Everything
on this board tied to VCC therefore sits at pack voltage, not 3.3 V. On the front there is a `473`
(47 kΩ) and a `472` (4.7 kΩ); the 4.7k belongs to the green LED, the 47k is almost certainly the
pull-up on ULT.

### Measuring (module disconnected, nothing hooked up)

| Measurement | Result | What you do |
|---|---|---|
| **EEP ↔ VCC** | open or ± 47 kΩ | wire from XIAO **3V3** to EEP — done |
| | near 0 Ω | J1 is closed: wick it off first, only then connect 3V3 |
| **ULT ↔ VCC** | does not matter | ULT stays floating |

### Chosen approach: do not desolder

`src/main.cpp` is therefore set to:

```c
#define HAVE_NSLEEP  0    // 1 = EEP on D1, only after J1 is removed
#define HAVE_NFAULT  0    // 1 = ULT on D8, only after the 47k is removed
```

**Leave ULT floating.** There is nothing else to do.

**EEP does have to be held high** — otherwise the internal 500 kΩ pulldown drags it low and the
driver stays asleep; the motor will never move.

> **Do not use J1 for this.** It connects EEP to VCC, and VCC on this board is VM: 8.4 V with a full
> pack. The logic pins of the DRV8833 — including nSLEEP — have an **absolute maximum of 7 V**
> (TI datasheet). Closing J1 therefore puts 1.4 V too much on it, precisely when the pack is full.

**Instead, run a single wire from the 3V3 pin of the XIAO to EEP.** That is L17 in the wire list,
only from 3V3 instead of from D1. nSLEEP then sits at 3.3 V, well within spec, the driver is
permanently enabled, and you do not have to solder anything on the module.

First measure **EEP ↔ VCC** with the module disconnected:

- **open, or ± 47 kΩ** → wire from 3V3 to EEP. Done. (With a 47k to VCC, 108 µA flows into the 3V3
  rail — negligible.)
- **near 0 Ω** → J1 was closed at the factory. Do **not** connect 3V3, because that would short the
  XIAO 3V3 rail against the pack. Wick the bridge off first — removing a solder bridge is a lot
  easier than removing an 0603 — and then run the wire to 3V3.

At boot this is safe: EEP goes high as soon as 3V3 is present, but IN1/IN2 are still high-Z at that
point and the DRV8833 has internal pulldowns on them. Both low = coast.

What this approach costs you:

- **without nSLEEP**: the driver is always on (~2 mA idle as long as SW1 is on) and you cannot clear
  a fault latch. The failsafe still works: on signal loss the firmware drives both inputs low and the
  locomotive coasts to a stop.
- **without nFAULT**: you do not see short circuits or overheating. That is less bad than it sounds —
  see the note at the bottom about what nFAULT does and does not catch.

The module already has **10 µF** on VCC (the orange block marked `106C`). C3/C4 are still worth it:
10 µF is little for the peak current of an N20.

The green LED on the module hangs off VCC through 4.7 kΩ and therefore burns continuously as long as
SW1 is on — about 1.4 mA out of your pack. If you do not want that, remove the 4.7 kΩ.

## Why the pins differ from the S3

The ESP32-C5 has exactly **one ADC unit**: ADC1, six channels, on GPIO1 through GPIO6. There is no
ADC2 — the Wi-Fi/ADC2 conflict of the S3 does not exist on this board. But of the **header pins** of
the XIAO C5, only **D0 (GPIO1)** is on that ADC. So the pack voltage divider has to go there.

That the motor control moves as a result is no problem: **AIN1 and AIN2 of the DRV8833 are digital
inputs.** Speed is the duty cycle of a 20 kHz square wave from the LEDC hardware, not an analog
voltage. The same holds for nSLEEP (output) and nFAULT (open-drain input). So the DRV8833 needs zero
ADC pins; the pack voltage is the only analog measurement in the whole locomotive.

**Two header pins stay empty.** Strapping pins on the C5 are GPIO2, GPIO7, GPIO25, GPIO27 and
GPIO28. On the header those are **D3 (GPIO7)** and **D2 (GPIO25)**. A strapping pin must have no
external pull-up or pulldown at reset — the chip reads that level as a boot option. That is why D2
and D3 stay unwired. In this build **D1 and D8 also stay free**: those were nSLEEP and nFAULT, and
they are not connected.

**D6 and D7 (GPIO11/GPIO12) are the UART.** Keep them free: that is where the boot log comes out and
where you hang a USB-TTL adapter when USB-CDC lets you down.

## Pinout, C5 versus S3

| Label | Net | S3 (rev C) | C5 (rev D) | Note |
|---|-----|---|---|---|
| D0 | VSENSE | GPIO1 = AIN1 | **GPIO1** | ADC1_CH0 — the only ADC on the header |
| D1 | ~~nSLEEP~~ | GPIO2 = AIN2 | **GPIO0** | **free** — nSLEEP is not driven |
| D2 | — | GPIO3 = headlight | **GPIO25** | **strapping — leave free** |
| D3 | — | GPIO4 = horn | **GPIO7** | **strapping — leave free** |
| D4 | AIN1 | GPIO5 = VSENSE | **GPIO23** | ordinary GPIO, PWM through the GPIO matrix |
| D5 | AIN2 | GPIO6 = nSLEEP | **GPIO24** | idem |
| D6/D7 | — | GPIO43/44 | **GPIO11/12** | UART — keep free |
| D8 | ~~nFAULT~~ | GPIO7 | **GPIO8** | **free** — nFAULT is not read |
| D9 | HEADLIGHT | — | **GPIO9** | ordinary GPIO |
| D10 | HORN | — | **GPIO10** | ordinary GPIO |

Sources: `variants/XIAO_ESP32C5/pins_arduino.h`, the ESP32-C5 datasheet (ADC1 = GPIO1…6) and the
Espressif hardware design guidelines / ESP-IDF GPIO page for the strapping pins.

## The buck — this changed compared to rev C

Rev C said "MP1584EN at **4.6 V**". That no longer holds now that a C5 is fitted, and honestly it was
already tight on the S3. The 5V pin of the XIAO feeds the on-board **SGM40567**, and that wants to
see roughly 4.5–5.5 V to consider its input valid. At 4.6 V you are on the edge: dip below it
briefly and the board falls back to the BAT pads — and nothing is connected there on the locomotive,
so the XIAO switches off.

**Set the buck to 5.0 V.** That it must be an *adjustable* MP1584EN and not a fixed Mini-560 still
stands, but for a different reason than given earlier: the Mini-560 no longer reaches 5 V below about
6.5 V input, and that is *above* the low-battery stop. The MP1584EN goes to 100 % duty and holds
5.0 V down to about 5.4 V input — well below the 6.6 V at which the firmware has already stopped.

## Order of assembly

1. L6–L31 first: everything except the pack.
2. **L1–L5 (pack, charger, star point) last**, and only then fit the cells.
3. Verification measurements at the bottom, and only then connect the motor.

Insulate each board (Kapton tape) before it goes in — everything ends up packed together inside the
chassis and body, with no exposed conductors allowed anywhere.

## Two grounds — this is not a detail

| Symbol | What | What hangs off it |
|---|---|---|
| **PWR** | star point at PACK− — one physical solder joint | L5 (pack−), L8 (buck IN−), L11 (DRV8833 GND), L13 (C3/C4 −) |
| **SIG** | the GND pin of the XIAO | L23 (LED1 cathode), L25 (BZ1), L27 (R4 + C1) |

The only connection between them runs **through the buck**: L10 (OUT− → XIAO GND) and L8 (IN− → star
point). **Do not add a second wire between them** — that creates a loop 1 A of motor current can run
through, and your ADC zero shifts with the throttle.

## Wire list

| # | Net | From | To | Colour | Wire |
|---|-----|---|----|---|---|
| L1 | PACK+ | pack positive contact | U1 charger **B+** | red | AWG20 |
| L2 | PACK+ | branch off L1 | SW1 **pin 2** (middle) | red | AWG20 |
| L3 | MID | jumper between the cells | U1 charger **BM** | yellow | AWG22 |
| L4 | PACK− | pack negative contact | U1 charger **B−** | black | AWG20 |
| L5 | PWR | branch off L4 | **PWR star point** | black | AWG20 |
| L6 | VBAT | SW1 **pin 1** | U2 buck **IN+** | red | AWG20 |
| L7 | VBAT | branch off L6 | U4 pin **VCC** (= VM) | red | **AWG20** |
| L8 | PWR | U2 buck **IN−** | **PWR star point** | black | AWG22 |
| L9 | 5V | U2 buck **OUT+** (5.0 V) | U3 XIAO **5V** | red | AWG24 |
| L10 | SIG | U2 buck **OUT−** | U3 XIAO **GND** | black | AWG24 |
| L11 | PWR | U4 DRV8833 **GND** | **PWR star point** — its own wire | black | **AWG20** |
| L12 | VBAT | C3/C4 positive side | **VM pin** of the DRV8833, < 2 cm | red | AWG22 |
| L13 | PWR | C3/C4 negative side | **GND pin** of the DRV8833, < 2 cm | black | AWG22 |
| L14 | VBAT | branch off L6/L7 | R3 top side (divider) | red | AWG26 |
| L15 | AIN1 | U3 XIAO **D4 / GPIO23** | U4 pin **IN1** | blue | AWG26 |
| L16 | AIN2 | U3 XIAO **D5 / GPIO24** | U4 pin **IN2** | blue | AWG26 |
| L17 | EEP high | U3 XIAO **3V3** | U4 pin **EEP** — see above | orange | AWG26 |
| ~~L18~~ | ~~nFAULT~~ | — | — | — | **dropped** — ULT stays floating |
| ~~L19~~ | ~~nFAULT~~ | — | — | — | **dropped** — no R5/C2 block |
| ~~L20~~ | ~~3V3~~ | — | — | — | **dropped** — no R5/C2 block |
| ~~L21~~ | ~~SIG~~ | — | — | — | **dropped** — no R5/C2 block |
| L22 | HEADLIGHT | U3 XIAO **D9 / GPIO9** | R1 47 Ω → LED1 **anode** | blue | AWG26 |
| L23 | SIG | LED1 **cathode** (short leg) | **SIG — GND pin of the XIAO** | black | AWG26 |
| L24 | HORN | U3 XIAO **D10 / GPIO10** | R2 100 Ω → BZ1 | blue | AWG26 |
| L25 | SIG | BZ1 other terminal | **SIG — GND pin of the XIAO** | black | AWG26 |
| L26 | VSENSE | divider tap (R3/R4 + C1) | U3 XIAO **D0 / GPIO1** | blue | AWG26 |
| L27 | SIG | R4 bottom side + C1 | **SIG — GND pin of the XIAO** | black | AWG26 |
| L28 | MOTOR A | U4 pin **OUT1** | M1 terminal A | purple | **AWG20** |
| L29 | MOTOR B | U4 pin **OUT2** | M1 terminal B | purple | **AWG20** |
| L30 | VBUS | J2 USB-C socket, **+** lead | U1 charger, **charge input +** (5 V) | red | AWG24 |
| L31 | VBUS− | J2 USB-C socket, **−** lead | U1 charger, **charge input −** | black | AWG24 |

**Do not connect:** SW1 pin 3, DRV8833 **IN3, IN4, OUT3, OUT4** (channel B) and **ULT**, XIAO
**D1, D2, D3, D6, D7, D8** and the BAT pads of the XIAO.

That makes **27 wires**: L1–L17, L22–L29 and L30–L31.

### L30/L31 — the external charge socket

The USB-C port on the charger board itself is not brought out through a wall. Instead, a separate
2-wire USB-C female connector (J2, see [`bom.md`](bom.md)) is mounted where you want the socket and
its two leads are soldered to the charge input of U1. Points to watch:

- **Polarity.** The red lead is VBUS (+5 V), the black one is ground. Reversed, you feed 5 V
  backwards into the charger.
- **CC resistors.** A 2-wire socket only carries VBUS and GND. It needs the two 5.1 kΩ CC
  pull-downs built in, otherwise a USB-C-to-USB-C charger will deliver nothing at all — the "3 A fast
  charge" type in the BOM has them. A USB-A-to-USB-C cable works either way.
- **This bypasses the charger's own USB-C connector**, not its charge circuitry: balancing, current
  limit and termination are unchanged.
- In `hardware/wiring-loco.svg` the socket is drawn as **J2** at the left, with L30/L31 running to
  the two charge input pads of U1; the charger's own USB-C port is marked unused.

**No wires, but do solder these:**

- **C5 10 nF** directly across the two motor terminals. Do not go larger: 100 nF already burns
  0.14 W in the H-bridge at 20 kHz PWM and produces current spikes of ~10 A through the bridge.
- ~~R6 100 kΩ pulldown on nSLEEP~~ — dropped: EEP is held hard at 3V3 via L17.

## The pack voltage measurement

External divider **R3 200 kΩ (top) / R4 100 kΩ (bottom)** on VBAT_SW, tap to D0, with **C1 100 nF**
from tap to SIG ground. Ratio 3.0 → 8.4 V becomes 2.80 V at the ADC.

Source impedance is 200k ∥ 100k = 67 kΩ, well above the <10 kΩ the SAR ADC wants to see. C1 supplies
the sampling charge locally, and the firmware additionally averages over 16 readings. Unlike the
remote, the tap here **is reachable** with a multimeter — that is your calibration point.

The firmware prints every 2 seconds:

```
pack 7840 mV (D0 2613 mV, ratio 3.000 x cal 1.000) | link 1 armed 1 fault 0
```

Calibration: multimeter on **VBAT_SW relative to SIG ground**, compare against the printed value, and
set `VDIV_CAL = multimeter / printed` in `main.cpp`. Cross-check with the tap: it must be exactly one
third of VBAT_SW.

**The on-board cell divider of the XIAO does nothing here.** It measures the BAT pads, and nothing is
connected to those on the locomotive. The firmware therefore drives GPIO26 low explicitly so the load
switch stays closed and the enable input does not float.

## Checks before fitting the cells

1. **Measure the module while disconnected**: EEP↔VCC and ULT↔VCC, per the table in "Your module"
   above.
2. Set the buck to **5.0 V** with a bench supply on the input, before mounting it.
3. Continuity check SW1 pin 1 → buck IN+ and → DRV8833 VM with SW1 on; **no** continuity with SW1
   off.
4. Measure the divider **before L14 is soldered**: R3+R4 ≈ 300 kΩ.
5. Verify there is **no** continuity between the PWR star point and the GND pin of the XIAO other
   than through the buck.
6. Fit the cells with the polarity verified; measure PACK+ ≈ 2× MID.

## Checks after switching on — motor still disconnected

Disconnect L28/L29 and measure without the motor first.

| Test point | Expected | Cross-check |
|---|---|---|
| VBAT (SW1 pin 1) | 6.0–8.4 V | pack voltage |
| buck OUT+ | 4.95–5.05 V | as adjusted |
| XIAO 3V3 | 3.25–3.35 V | internal LDO |
| divider tap (D0) | exactly one third of VBAT | 8.4 V → 2.80 V |
| printed pack value | within ~2 % of the multimeter | otherwise adjust `VDIV_CAL` |
| EEP pin of the module | 3.3 V | held high via L17 — driver always awake |
| ULT pin of the module | 8.4 V (= VCC) | 47 kΩ pull-up on the module, not connected |
| XIAO D1 and D8 | floating, no wire | both pins stay free |
| OUT1/OUT2 at rest | both low (brake) | IN1 = IN2 = 0 with the motor stopped |

Then connect the motor and apply throttle carefully with the locomotive on blocks. A free-running N20
draws 60–100 mA, stalled 0.7–1 A.

## Parts not yet in the BOM

| Part | Value | Reason |
|---|---|---|
| C1 | 100 nF ceramic (X7R) | 67 kΩ source impedance of the divider versus the <10 kΩ the ADC wants |
| C3 | 100 µF low-ESR electrolytic, ≥ 16 V | HF decoupling of the H-bridge, 2 cm loop. **Not** a brownout buffer: at 1 A, 100 µF holds the voltage for only ~100 µs per volt |
| C4 | 100 nF ceramic | in parallel with C3 |
| C5 | 10 nF ceramic | noise suppression across the motor terminals |
| — | switch rated ≥ 2 A | replaces the SS12D00 |
| — | fuse or PTC, 2 A | directly after SW1 |
| — | buck MP1584EN | adjustable, set to **5.0 V** |
| — | wire AWG20/22/24 | the BOM only lists AWG26 |

## Firmware — `firmware/loco/` (PlatformIO)

Same setup as the remote: `platformio.ini` with the pioarduino fork (`55.03.311`, board
`seeed_xiao_esp32c5`) and `src/main.cpp`. Build and flash:

```
pio run -t upload
pio device monitor -b 115200
```

What changed compared to rev C:

- pins by **label** (D0…D10) instead of bare GPIO numbers, with the C5 mapping in the comments
- `esp_wifi_set_band_mode(WIFI_BAND_MODE_2G_ONLY)` before `esp_wifi_set_channel()`
- the on-board cell divider is disabled (GPIO26 low)
- `packMv()` averages over 16 readings and has a `VDIV_CAL` trim factor
- a calibration line over USB, so you can check the measurement instead of guessing

Unchanged from rev C, and still important:

- IN1/IN2 are driven low as the very first thing in `setup()`: the motor cannot twitch at boot. The
  hardware nSLEEP can no longer enforce that, so this is now the only boot protection
- **neutral lockout**: after power-up or signal loss the locomotive only drives once the throttle
  stick has been at centre one time
- **`currentSpeed` is held at zero while driving is not allowed** — with `HAVE_NSLEEP 0` the line
  `if (!mayDrive) tgt = 0;` does that work; otherwise the ramp counter keeps running during a fault
  and the locomotive jumps to full duty in a single loop on recovery
- fault counter with debounce, retry after 1 s, permanent shutdown after 5 faults in 10 s
- hysteresis on the low-battery stop (6600 / 6900 mV, 3 consecutive readings)
- `ledcWriteTone()` only on a change; `WiFi.setSleep(false)`

**What you give up by not connecting nFAULT:** the overcurrent protection of the DRV8833 sits at
2–3.3 A and a stalled N20 stays around 1 A. So nFAULT catches short circuits and overheating, not a
stalled locomotive — precisely the case you expect with a toy train. The firmware already covers that
with the low-battery threshold and the link timeout. What remains: a genuine short in the motor
wiring will show up as a hot driver, not as a fault message.

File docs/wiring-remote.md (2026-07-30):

# Remote — wire list rev F (XIAO ESP32-**C5**)

Goes with [`hardware/wiring-remote.svg`](../hardware/wiring-remote.svg) and
[`firmware/remote/src/main.cpp`](../firmware/remote/src/main.cpp). Successor to rev D (S3).
The numbering W1–W19 is kept identical to rev D; **W5, W8 and W9 are dropped**.

> **Still building on the S3?** Then use rev D. This list breaks the battery measurement on an S3.
> The **locomotive now runs on a C5 as well** — see [`wiring-loco.md`](wiring-loco.md).
>
> **Rev F versus rev E:** the two LEDs move from D2/D3 to **D9/D10**. GPIO25 and GPIO7 are strapping
> pins on the C5; see "Strapping pins" below.

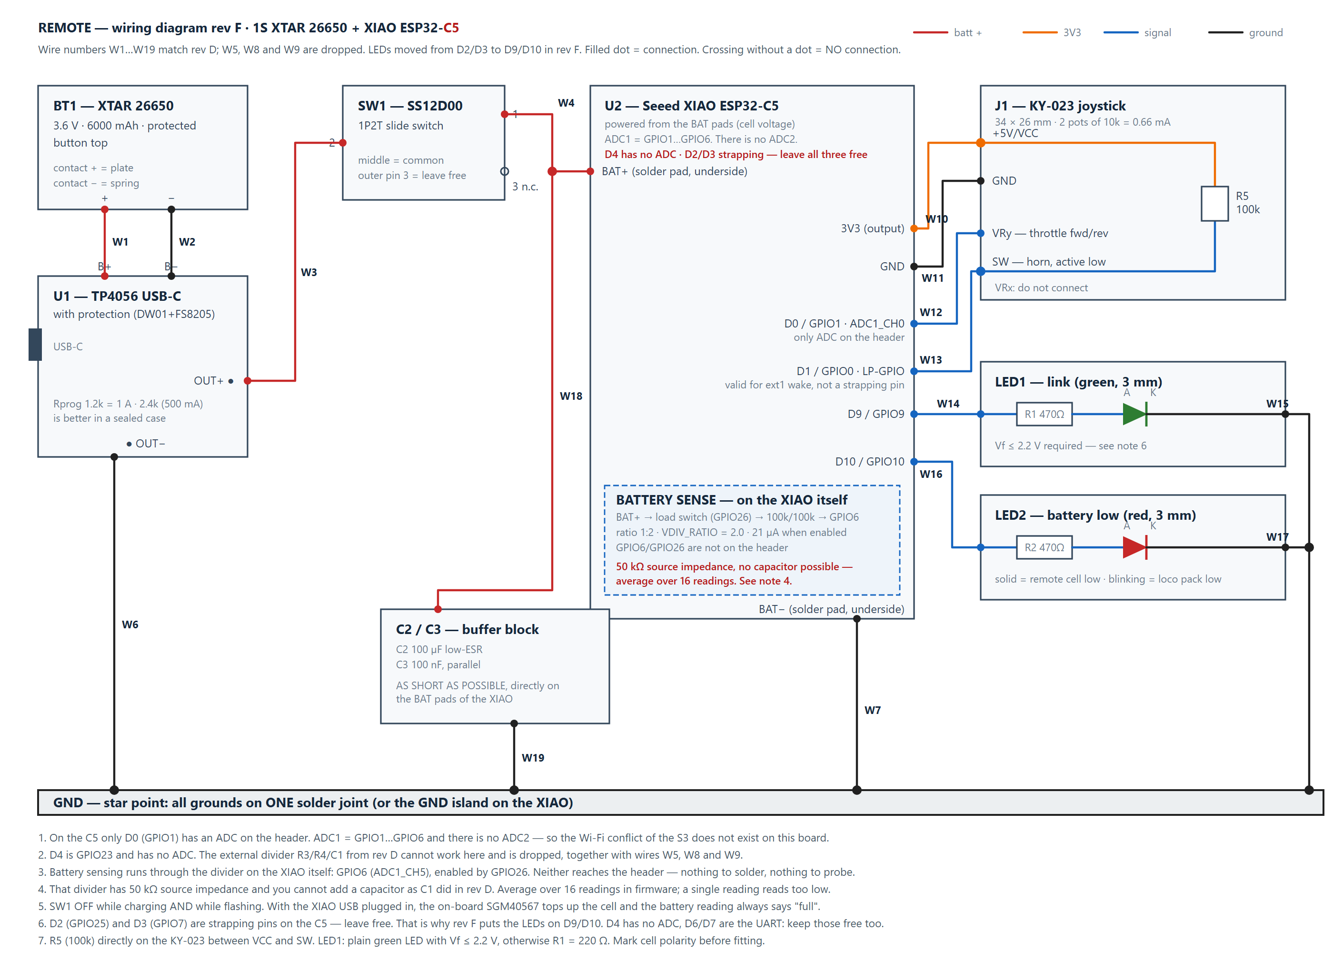
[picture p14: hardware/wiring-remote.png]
Remote wiring diagram rev F


## What changed compared to rev D

| Item | Rev D (S3) | Rev E/F (C5) | Why |
|---|---|---|-----|
| Battery sense | external divider R3/R4 + C1 → D4 | **divider on the XIAO itself** (GPIO6, enable GPIO26) | D4 is GPIO23 on the C5 and has no ADC |
| W5, W8, W9 | three wires | **dropped** | they belong to the external divider |
| R3, R4, C1 | in the BOM | **dropped** | idem |
| JOY_SW | D1 = GPIO2 | D1 = **GPIO0** | different board, same path |
| LED_LINK | D2 = GPIO3 | **D9 = GPIO9** | D2/GPIO25 is a strapping pin |
| LED_BATT | D3 = GPIO4 | **D10 = GPIO10** | D3/GPIO7 is a strapping pin |
| Wake from deep sleep | `esp_sleep_enable_ext0_wakeup()` | `esp_sleep_enable_ext1_wakeup()` | ext0 does not exist on RISC-V |
| Radio band | implicitly 2.4 GHz | **locked explicitly** to 2.4 GHz | the C5 is dual-band; both ends must be on the same band |

By **label** the pins sit in the same place. If you already soldered rev D, you do not need to move
any wire for the joystick or the LEDs — only remove the divider.

## Pinout, C5 versus S3

| Label | Net | S3 | C5 | Note on the C5 |
|---|-----|----|----|---|
| D0 | JOY_Y | GPIO1 | GPIO1 | ADC1_CH0 — **the only ADC on the header** |
| D1 | JOY_SW | GPIO2 | **GPIO0** | LP-GPIO, valid for ext1 wake, not a strapping pin |
| D2 | — | GPIO3 | **GPIO25** | **strapping — leave free** |
| D3 | — | GPIO4 | **GPIO7** | **strapping — leave free** |
| D4 | — | GPIO5 | **GPIO23** | **no ADC** — do not use |
| D6/D7 | — | GPIO43/44 | **GPIO11/12** | UART — keep free |
| D9 | LED_LINK | — | **GPIO9** | ordinary digital output |
| D10 | LED_BATT | — | **GPIO10** | ordinary digital output |
| — | VSENSE | — | GPIO6 | divider on the XIAO, ADC1_CH5 |
| — | VSENSE_EN | — | GPIO26 | enables that divider, HIGH = on |

Source for the label mapping and the two battery pins: `variants/XIAO_ESP32C5/pins_arduino.h` in
arduino-esp32 (`D0=1 D1=0 D2=25 D3=7 D4=23`, `BAT_VOLT_PIN=6`, `BAT_VOLT_PIN_EN=26`).

## Strapping pins — why the LEDs moved

Strapping pins on the ESP32-C5 are **GPIO2, GPIO7, GPIO25, GPIO27 and GPIO28**. On the XIAO header
those are **D3 (GPIO7)** and **D2 (GPIO25)** — exactly where rev E had the two LEDs.

Why that is a bad idea: at reset the GPIO is high-Z and the chip reads the pin level for about 3 ms.
With an LED and 470 Ω to ground attached, the pin settles at roughly the forward voltage of the LED,
about 1.9 V. That sits between the thresholds for low (~0.8 V) and high (~2.5 V), so what the chip
reads is undefined.

The boot mode itself depends on GPIO26/27/28 and not on these two, so the odds of the board failing
to start are small. But D9 and D10 are free on this board as ordinary GPIOs, so there is no reason to
take the risk. **Move two wires and be done.**

If you already soldered rev E: move W14 from D2 to D9, and W16 from D3 to D10. The firmware in
`main.cpp` is already on the new pins.

## The battery measurement — read this before soldering

**The C5 has only one ADC unit.** ADC1, six channels, on GPIO1 through GPIO6. There is **no ADC2**.
Two consequences:

1. The Wi-Fi/ADC2 conflict that applied on the S3 does not exist on this board. The warning from
   rev D does not apply here.
2. Of the header pins, only **D0 (GPIO1)** can measure analog. So the joystick Y axis has to sit
   there — there is no alternative. D4 (GPIO23) has no ADC hardware, so the external divider from
   rev D cannot work on this board. That is why it is dropped; it is not a software choice.

The XIAO C5 has the measurement on board: **BAT+ → load switch (GPIO26) → 100 kΩ / 100 kΩ → GPIO6**.
Ratio **1:2**, so `VDIV_RATIO = 2.0f`. The enable is **active high**.

> The two open items from the previous version of this list are hereby closed: `VDIV_RATIO 2.0f` is
> correct (it happens to be the same ratio as the dropped external 100k/100k divider), and
> `digitalWrite(BAT_VOLT_PIN_EN, HIGH)` is the right polarity.

### What does need attention

**The source impedance has not disappeared, it has only become unreachable.** 100 kΩ ∥ 100 kΩ =
50 kΩ, exactly the same 50 kΩ that made C1 (100 nF) necessary in rev D. GPIO6 does not reach the
header, so you **cannot** add a capacitor now. The only remedy is in firmware: **average over 16
readings**. Seeed recommends this in their own example too, on the grounds that transmitting puts
spikes on the reading. The firmware does that now; a single reading every 2 s reads structurally too
low.

**You cannot verify the measurement with a multimeter.** In rev D the check table said "measure the
divider tap on D4 = exactly half of BAT+". That point no longer exists. That is why the firmware
prints a calibration line over USB every 2 seconds:

```
cell 3847 mV (pin 1923 mV, ratio 2.000 x cal 1.000) | loco 7620 mV
```

Calibrate like this — USB may stay plugged in:

1. Cell fitted, **SW1 on**, XIAO USB into the PC, serial monitor open at 115200.
2. Put a multimeter on **BAT+ relative to GND** and read the printed cell value at the same moment.
3. `VDIV_CAL = multimeter / printed cell value`. Put that value in `main.cpp` and reflash.
4. Verify with a second reading at a different cell voltage.

That the SGM40567 is topping up the cell at that moment makes no difference for **calibration**: the
multimeter and the on-board divider measure the same node at the same time, so the charge current
cancels out. It only matters for the **absolute** value — see below.

Two 100 kΩ resistors are typically ±1 %, so the ratio can be off by up to ~2 % — at 4.2 V that is
~84 mV. For a threshold at 3300 mV that is not dramatic, but it does decide whether the red LED comes
on too early or too late.

**With the XIAO USB plugged in you read the charge voltage, not the resting voltage.** The on-board
SGM40567 then tops up the cell and pulls BAT+ towards 4.2 V. The battery measurement therefore always
reads "full" and the red LED never comes on. For functional testing (joystick, link, LEDs, packets)
that is no problem, and for calibrating `VDIV_CAL` it is not either. If you want to see the **resting
voltage** or test the low-battery threshold, unplug USB — or use a USB cable with the 5 V conductor
cut (data only), which keeps the COM port working while the XIAO runs off the cell.

With **SW1 off** and USB plugged in you do get serial output, but BAT+ is disconnected from the cell.
The reading is then meaningless: the charger is driving an open node. Fine for flashing, not for
measuring.

**The divider is pinched off in deep sleep.** The firmware drives GPIO26 low and latches it with
`gpio_hold_en()` just before `esp_deep_sleep_start()`; on wake, `gpio_hold_dis()` comes first in
`setup()`. That saves the 21 µA the 100k/100k would otherwise draw permanently. Check on the first
build whether that really works: measure the deep-sleep current. If you end up ~21 µA above
expectation, the hold is not taking.

## Order of assembly

1. W3–W19 first: power, ground, signals, buffer block.
2. **W1–W2 (cell → TP4056) last.** As long as the cell is not connected, nothing can be damaged.
3. Checks below, and only then fit the cell.

## Wire list

| # | Net | From | To | Colour | Wire |
|---|-----|---|----|---|---|
| W1 | CELL+ | BT1 positive contact (plate) | U1 TP4056 **B+** | red | AWG20–22 |
| W2 | CELL− | BT1 negative contact (spring) | U1 TP4056 **B−** | black | AWG20–22 |
| W3 | VBAT | U1 TP4056 **OUT+** | SW1 **pin 2** (middle) | red | AWG22 |
| W4 | VBAT_SW | SW1 **pin 1** (outer) | U2 XIAO **BAT+** pad (underside) | red | AWG24–26 |
| ~~W5~~ | ~~VBAT_SW~~ | — | — | — | **dropped** (divider) |
| W6 | GND | U1 TP4056 **OUT−** | GND star point | black | AWG22 |
| W7 | GND | U2 XIAO **BAT−** pad (underside) | GND star point | black | AWG24–26 |
| ~~W8~~ | ~~GND~~ | — | — | — | **dropped** (divider) |
| ~~W9~~ | ~~VSENSE~~ | — | — | — | **dropped** (divider) |
| W10 | 3V3 | U2 XIAO **3V3** | J1 KY-023 **+5V/VCC** | orange | AWG26 |
| W11 | GND | U2 XIAO **GND** | J1 KY-023 **GND** | black | AWG26 |
| W12 | JOY_Y | J1 KY-023 **VRy** | U2 XIAO **D0 / GPIO1** | blue | AWG26 |
| W13 | JOY_SW | J1 KY-023 **SW** | U2 XIAO **D1 / GPIO0** | blue | AWG26 |
| W14 | LED_LINK | U2 XIAO **D9 / GPIO9** | R1 → LED1 **anode** (green) | blue | AWG26 |
| W15 | GND | LED1 **cathode** (short leg) | GND star point | black | AWG26 |
| W16 | LED_BATT | U2 XIAO **D10 / GPIO10** | R2 470 Ω → LED2 **anode** (red) | blue | AWG26 |
| W17 | GND | LED2 **cathode** (short leg) | GND star point | black | AWG26 |
| W18 | VBAT_SW | C2/C3 positive side | XIAO **BAT+** pad — **as short as possible** | red | AWG24 |
| W19 | GND | C2/C3 negative side | XIAO **BAT−** pad — **as short as possible** | black | AWG24 |

**Do not connect:** SW1 pin 3, KY-023 VRx, XIAO **D2, D3, D4, D6, D7**, and all remaining XIAO pins.

**R5 (100 kΩ)** is not a wire: solder it directly on the KY-023 between the pins **VCC** and **SW**.
**C2/C3** belong physically on the BAT pads of the XIAO itself; W18/W19 are only in the list to make
the topology unambiguous — they are not 10 cm flying leads.

## Parts

Compared to rev D, **R3, R4 and C1 are dropped.** The rest stays:

| Part | Value | Reason |
|---|---|---|
| C2 | 100 µF low-ESR electrolytic (≥ 6.3 V) | ESP-NOW draws peaks of 250–350 mA. Cell → protection FETs → slide switch → thin wire gives a 50–150 mV dip. With a nearly empty cell the XIAO then drops through its brownout — exactly when the low-battery warning should be working. |
| C3 | 100 nF ceramic | HF decoupling in parallel with C2. |
| R5 | 100 kΩ | External pull-up on D1. The internal pull-up disappears as soon as the chip enters deep sleep; without R5, D1 floats and waking on a joystick press is unreliable. |

Alternative to R5 without an extra part: `rtc_gpio_pullup_en(GPIO_NUM_0);` just before
`esp_deep_sleep_start()`. **Watch the pin number:** rev D said `GPIO_NUM_2`, which was the S3.

## Operating rules

1. **SW1 OFF while charging.** OUT+ and B+ are the same track on the TP4056, so it sees the load of
   the XIAO (~80–100 mA) as charge current. The termination threshold (≈C/10 = 100 mA at 1 A) is then
   never reached; the CHRG LED never goes out and the cell stays at 4.2 V.
2. **SW1 OFF while flashing.** The cell is then disconnected from BAT+ and USB powers only the XIAO.
   That way two chargers never work on the same cell at once, and you do not accidentally measure the
   charger instead of the cell.
3. **Check cell polarity before fitting.** The printed bay accepts the 26650 the wrong way round too.
   With reversed polarity the body diodes in the FS8205 conduct and the TP4056 is destroyed; the
   protection inside the cell does not prevent that.

## Checks before connecting the cell

1. Continuity check OUT+ → XIAO BAT+ with SW1 on; **no** continuity with SW1 off.
2. Resistance between OUT+ and OUT−: expect **> 100 kΩ**, not "infinite" — the module has internal
   paths (DW01 supply, status LEDs).
3. The divider check from rev D is **dropped**; there is no external divider any more and GPIO6 is
   not reachable.
4. Only then solder W1/W2 and fit the cell — with the polarity verified.

## Checks after switching on

| Test point | Expected | Cross-check |
|---|---|---|
| XIAO BAT+ relative to GND | cell voltage, 3.0–4.2 V | multimeter — this is your calibration reference |
| printed cell value over USB | within ~2 % of the multimeter | otherwise adjust `VDIV_CAL` |
| XIAO 3V3 | 3.25–3.35 V | internal LDO |
| KY-023 VRy at rest | ± 1.65 V | half of 3V3; the firmware calibrates the centre at boot — **release the stick during boot** |
| LED current | 2.5–3.0 mA per LED | (3.3 V − Vf) / 470 Ω, with Vf ≈ 1.9–2.2 V |
| consumption, SW1 off | a few tens of µA | leakage of TP4056/DW01 only — measure it, do not assume |
| consumption, on + deep sleep | about 0.7 mA | dominated by the 0.66 mA of the two 10k pots of the KY-023 on 3V3. If there is ~21 µA on top of that, the hold on GPIO26 is not taking and the cell divider keeps running. |

On 6000 mAh, 0.7 mA is about 10 months of standby. If you want it lower: feed the KY-023 from a GPIO
instead of 3V3. In that case **R5 must no longer be on the module** but as a discrete resistor from
the fixed 3V3 to D1 — otherwise the pull-up dies with the module supply and the wake stops working.

## Still open — not the battery measurement

**The throttle stick is asymmetric.** VRy runs 0–3.3 V, but the ADC saturates below 3.3 V.
`joyCenter` therefore ends up above 2048 while `readThrottle()` divides hard by 2048: forward never
reaches full throttle, reverse hits −1000 before the end stop. This is **not yet** in the firmware.
Scaling per direction fixes it:

```c
long v = (a > joyCenter) ? (a - joyCenter) * 1000L / (4095 - joyCenter)
                         : (a - joyCenter) * 1000L / joyCenter;
```

**Green LED.** 470 Ω is right for red (Vf ≈ 1.9 V → 3.0 mA). A bright green InGaN LED has
Vf ≈ 3.0–3.2 V and barely lights up on 3.3 V through 470 Ω. Use one with Vf ≤ 2.2 V, or R1 = 220 Ω.

**The TP4056 at 1 A** dissipates ≈1.8 W inside a sealed PETG case. Rprog 1.2 kΩ → 2.4 kΩ makes it
500 mA (charge time ≈13 h).

## Radio

The C5 is dual-band (Wi-Fi 6, 2.4 + 5 GHz). The firmware therefore locks the band explicitly with
`esp_wifi_set_band_mode(WIFI_BAND_MODE_2G_ONLY)` before `esp_wifi_set_channel()`. Without that line
channel 1 can end up on the 5 GHz band and the locomotive sees nothing. The ESP-NOW protocol is
unchanged: same `MAGIC`, same packet layout, channel 1.

## Build environment

The C5 is only supported from Arduino-ESP32 core 3.3 / IDF 5.5 onwards. `platformio.ini` therefore
points at pioarduino 55.03.311. That requires PlatformIO Core ≥ 6.1.19; if the `pio` on your PATH is
older, call the one in `%USERPROFILE%\.platformio\penv\Scripts\pio.exe`.

## Sources

- Pin mapping and battery pins: `variants/XIAO_ESP32C5/pins_arduino.h`, arduino-esp32
- ADC1 channels (GPIO1–6, one ADC unit) and LP_GPIO0–LP_GPIO6: ESP32-C5 datasheet, Espressif
- Strapping pins GPIO27/GPIO28: esptool "Boot Mode Selection — ESP32-C5", Espressif
- On-board divider 2× 100 kΩ, 1:2, `BAT_VOLT_PIN_EN` high, range 0–3300 mV: Seeed Studio wiki,
  "Getting Started with Seeed Studio XIAO ESP32-C5"
- 16× averaging against spikes while transmitting: Seeed Studio wiki, "How to check the battery
  voltage"
- Strapping pins GPIO2/7/25/27/28: Espressif ESP-IDF "GPIO & RTC GPIO — ESP32-C5" and the hardware
  design guidelines schematic checklist

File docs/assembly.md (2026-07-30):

# Printing and assembly

> **Status note.** The mechanical instructions below were written for the earlier OpenSCAD/FreeCAD
> version of the parts. The mechanics (drive concept, axles, magnets, screw positions) are unchanged,
> but the current geometry lives in the Rhino/STEP files in [`../cad/`](../cad/), and the body is now
> split into a chassis plus three glued top pieces instead of one part. Print-ready meshes are in
> [`../stl/`](../stl/) — check the details below against that geometry before printing. The
> electrical side is current: see [`wiring-loco.md`](wiring-loco.md) and
> [`wiring-remote.md`](wiring-remote.md).

## Drive concept — read before printing

The N20 is 24 mm long; the space between the wheels is only 21 mm, so the motor **cannot** sit on the
axle. It sits in a tunnel **above** the rear wheels and drives the rear-right wheel 1:1 through an
18×2 O-ring belt (pulley on the motor shaft → grooved hub on the wheel). Belt tension pulls the motor
into its seat. One driven wheel with a rubber tyre (the second O-ring) is enough — the battery weight
sits on top of it.

Speed: 150 rpm × Ø21 effective ≈ **16 cm/s**, capped further in firmware via `MAX_DUTY`.

## Print settings

PETG, 0.4 nozzle, 0.2 mm layers, 3 perimeters, 20 % infill.

| File in [`../stl/`](../stl/) | Qty | Orientation | Notes |
|---|-----|---|---|
| `loco-chassis.stl` | 1 | as-is (plate down) | supports under the motor box + coupler arms |
| `loco-boiler.stl` | 1 | as-is | supports in the wheel arches |
| `loco-cab.stl` | 1 | as-is | supports at the window tops |
| `loco-front.stl` | 1 | as-is | short part, prints flat against the plate |
| `loco-wheel-plain.stl` | 3 | as-is | 2× front (press onto the Ø3 rod), 1× rear left with an M3 washer against the boss |
| `loco-wheel-driven.stl` | 1 | as-is (outer face down) | rear right, belt hub inward |
| `loco-pulley.stl` | 1 | as-is | D-bore, push onto the N20 shaft |
| `remote-bottom.stl` / `remote-top.stl` | 1+1 | flat face down (top printed upside-down) | no supports needed; the small board-retention lips are short flat overhangs and print fine |

Wall count ≥ 3 for the wheels — the hub takes the drive load.

## Assembly — locomotive

1. **Chassis**: press the AA spring/plate contacts into the battery-bay end slots (springs at one
   end, plates at the other; the two cells sit antiparallel — jumper the far-end contacts to make the
   series link, and take the middle tap from that jumper for the balance wire).
2. **Motor**: push the pulley onto the N20 D-shaft, slide the motor into the tunnel from the left
   side, shaft through the hole in the right end wall. Seat the pulley as close to the end wall as
   possible. A dab of hot glue at the tunnel mouth.
3. **Belt**: loop one 18×2 O-ring from the pulley down through the belt window onto the driven-wheel
   hub groove, then screw the driven wheel (M3×12 + washer) into the right stub pilot. Left wheel:
   M3×12 + washer. Stretch the second O-ring into the tread groove first.
4. **Front axle**: push the Ø3×32 rod through the chassis bore, press a wheel onto each end
   (0.1–0.2 mm clearance under the rod so wheels and rod spin together).
5. **Electronics**: there is no e-shelf tray any more. The boards are mounted in the chassis, and the
   space inside the boiler and the cab takes the rest — with a bit of folding, everything fits.

   **Insulate every board before fitting it**, for example with Kapton tape, and make sure there are
   no exposed conductors anywhere: the boards end up pressed against each other and against the
   printed walls, with a 2S pack behind them. Check that no strand sticks out of a solder joint and
   that every splice is covered by heat-shrink.

   The power switch stands **vertically** in the slot near the right rear corner. Wire per
   [`wiring-loco.md`](wiring-loco.md) — **firmware first, wiring second**, and follow the order of
   assembly in that document.

   **Charge socket**: the USB-C port of the 2S charger board is not brought out through the wall.
   Instead, use a separate 2-wire USB-C female connector with a snap-groove buckle (see
   [`bom.md`](bom.md)) and solder its two leads to the charge input of the charger board. That leaves
   the charger free to sit wherever it fits and puts the socket where you want it.
6. **Magnets**: check the polarity against a real Brio wagon **before** gluing the Ø10×3 magnets into
   the coupler pockets (epoxy).
7. **Body**: the body is three printed pieces on top of the chassis — front, boiler and cab. The
   split exists so that each piece can be printed without much support; **glue the three together
   with superglue (cyanoacrylate)**. Dry-fit them first, and glue with the parts held against the
   chassis so the joints line up with it. The assembled body then drops over the chassis and is
   secured with 2× M3×12 from below into the internal pillars. Both screws sit off-centre: front at
   y = +10, rear at y = −12 (diagonally opposed), keeping the rear wall free for the charger board.
   The cab front wall has a notch that fits over the motor box.

## Assembly — remote

Both boards sit in rigid pockets — the case wall takes the USB-C plug forces (the plug overmould
bottoms out on the wall, a backstop takes the insertion force), and the boards are held down by lips
plus pillars in the top shell.

1. Press the 26650 spring/plate contacts into the end-wall slots, drop the cell into the cradle.
2. **TP4056** (long axis across the case, USB-C at the side wall): slip its rear edge under the lip
   on the pocket backstop with the USB end tilted up, then lower the USB end until the connector sits
   in the side-wall opening. Route the B+/B− wires through the notch in the backstop or over it.
3. **XIAO**: solder the BAT wires to the underside pads first. Tilt the board nose-down, slide the
   USB-C end under the two lips at the end wall, drop the rear onto the ledges. The wires run in the
   channel under the board and out through the backstop notch. Stick a 1–2 mm foam pad on top of the
   RF shield.
4. Joystick screwed to the 4 posts under the top-shell hole, LEDs into the top holes, switch into its
   slot.
5. Close the shells: the top-shell pillars press the XIAO (via the foam pad) and the TP4056 front
   edges down. 4× M3×12 from the top.

## Before printing — verify against your own set

1. **Magnet height**: measure the magnet centre height of one of your wagons above the rail surface;
   the design assumes 13 mm above track top.
2. **Tightest curve**: if the locomotive binds on small-radius curves, increase the wheel chamfer to
   2 mm.
3. **Cell length**: protected 14500 cells are 50.5 mm, 0.5 mm longer than a standard AA. Check the
   bay before printing the full chassis.

## Safety notes

- The 2S charger must be an IP2326-type **balance** board wired B−/BM/B+. Never charge the pack
  through a plain 1S board.
- Cells are protected, but the low-battery auto-stop (6.6 V trip / 6.9 V clear) is the primary
  over-discharge guard — do not disable it.
- Body screws on: no child access to the cells. Charging only under supervision.
- Master switch off while charging and while flashing, on both units.

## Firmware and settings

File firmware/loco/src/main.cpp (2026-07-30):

/*
 * Brio RC Locomotive — receiver / drive controller               rev D (2026-07-28)
 * Board: Seeed XIAO ESP32-C5  (PlatformIO: env xiao_esp32c5, core 3.3.x)
 *
 * Power: 2S (2x XTAR 14500, protected), 6.0–8.4 V, through an adjustable buck
 *        set to 5.0 V into the 5V pin of the XIAO.
 * Motor: N20 6 V via DRV8833 channel A, PWM capped at MAX_DUTY
 * Link:  ESP-NOW broadcast, filtered on MAGIC, channel 1, locked to 2.4 GHz
 *
 * ---------------------------------------------------------------------------
 * WHY THE PINOUT DIFFERS FROM THE S3 (rev C)
 *
 * The ESP32-C5 has exactly ONE ADC unit: ADC1, six channels, GPIO1..GPIO6.
 * There is no ADC2 — the Wi-Fi/ADC2 conflict of the S3 does not exist here.
 * Of the XIAO C5 header pins, only D0 (GPIO1) is on that ADC. The pack voltage
 * divider therefore MUST go to D0, which pushes the motor control elsewhere.
 * That is harmless: AIN1/AIN2 of the DRV8833 are digital inputs (speed = duty
 * cycle of a square wave), as are nSLEEP and nFAULT. So the pack voltage is
 * the only analog measurement in the entire locomotive.
 *
 * Strapping pins on the C5 are GPIO2, GPIO7, GPIO25, GPIO27 and GPIO28.
 * On the header those are D3 (GPIO7) and D2 (GPIO25): leave them EMPTY. Two
 * signals here carry an external resistor (R5 pull-up on nFAULT, R6 pulldown
 * on nSLEEP) and that would drag a strapping pin to the wrong level at reset.
 * D6/D7 (GPIO11/GPIO12) are the UART: keep free for the boot log and debug.
 * ---------------------------------------------------------------------------
 */

#include <Arduino.h>
#include <WiFi.h>
#include <esp_now.h>
#include <esp_wifi.h>

// ---------- pins (XIAO C5 silkscreen -> GPIO) ----------
//   D0=GPIO1  D1=GPIO0  D2=GPIO25* D3=GPIO7*  D4=GPIO23 D5=GPIO24
//   D6=GPIO11 D7=GPIO12 D8=GPIO8   D9=GPIO9   D10=GPIO10      (* = strapping)
// The silkscreen on the black 6+6-pin DRV8833 module is mangled English:
//   EEP = nSLEEP   ULT = nFAULT   IN1/IN2 -> OUT1/OUT2 = channel A
#define PIN_VSENSE   D0   // GPIO1,  ADC1_CH0 <- divider 200k/100k (Vpack/3) + 100 nF
#define PIN_NSLEEP   D1   // GPIO0  -> module EEP  (NOT wired: EEP is tied to 3V3)
#define PIN_IN1      D4   // GPIO23 -> module IN1  (PWM)
#define PIN_IN2      D5   // GPIO24 -> module IN2  (PWM)
#define PIN_NFAULT   D8   // GPIO8  <- module ULT  (NOT wired: ULT left floating)
#define PIN_LED      D9   // GPIO9  -> headlight (47R -> LED -> SIG ground)
#define PIN_BUZZ     D10  // GPIO10 -> passive buzzer (100R)

// ---------------------------------------------------------------------------
// BUILD SWITCHES for the black DRV8833 module
//
// On this board VCC is the same net as VM, so 8.4 V. Solder bridge J1 connects
// EEP to VCC, and there is a 47k pull-up from ULT to VCC. As long as those are
// present you must NOT connect EEP or ULT to a 3.3 V GPIO.
//
// CURRENTLY 0/0: EEP and ULT are not connected to a GPIO in this build.
//
// EEP must then be held HIGH, otherwise the internal 500k pulldown drags it low
// and the driver stays asleep. Do NOT do that with J1: it connects EEP to
// VCC = VM = 8.4 V, while the logic pins of the DRV8833 have an absolute
// maximum of 7 V. Instead, run a wire from the 3V3 pin of the XIAO to EEP
// (L17 in the wire list).
//
// Set these to 1 only after removing J1 / the 47k and running the wire to D1
// respectively D8.
#define HAVE_NSLEEP  0    // 1 = EEP on D1, only after J1 is removed
#define HAVE_NFAULT  0    // 1 = ULT on D8, only after the 47k is removed
// ---------------------------------------------------------------------------

// The on-board cell divider of the XIAO (GPIO6 via load switch GPIO26) measures
// the BAT pads. On the locomotive NOTHING is connected there — the board is fed
// through the 5V pin. So we explicitly disable that divider, otherwise the
// enable input floats. GPIO26 is a strapping pin: driving it after boot is fine,
// hanging an external resistor on it is not (and cannot be done anyway, it is
// not on the header).
#define PIN_BATSENSE_EN  BAT_VOLT_PIN_EN   // GPIO26

// ---------- tuning ----------
#define WIFI_CHANNEL     1
#define MAGIC            0xB210C0DEUL  // must match the remote
#define FAILSAFE_MS      400
#define MAX_DUTY         75            // % of 8.4 V -> ~6.3 V on the N20. Never above 80.
#define SLEW_PER_LOOP    40            // acceleration ramp, units per 20 ms
#define PWM_FREQ         20000         // 20 kHz, inaudible
#define PWM_RES          10            // bits -> duty 0..1023

// ---------- pack voltage measurement ----------
// External divider R3 200k (top) / R4 100k (bottom) on VBAT_SW, tap to D0,
// with C1 100 nF from tap to SIG ground. Source impedance 200k||100k = 67 kOhm,
// well above the <10 kOhm the SAR ADC wants to see: C1 supplies the sampling
// charge locally and we average over 16 readings.
#define VDIV_RATIO       3.0f          // (200k + 100k) / 100k
// Trim factor: measure VBAT_SW with a multimeter, compare against the printed
// line and set VDIV_CAL = (multimeter / printed). Leave at 1.000f until measured.
#define VDIV_CAL         1.000f
#define VSENSE_SAMPLES   16

// Low-battery threshold with hysteresis. 6600 mV = 3.3 V/cell.
// The buck (MP1584EN set to 5.0 V) holds its output down to about 5.4 V input,
// so this threshold sits well above the brownout limit.
#define LOW_BATT_TRIP_MV   6600
#define LOW_BATT_CLEAR_MV  6900
#define LOW_BATT_STRIKES   3

// ---------- fault handling ----------
#define WAKE_US          2000UL        // tWAKE of the DRV8833 is max 1 ms
#define FAULT_DEBOUNCE   3
#define FAULT_RESET_MS   1000UL
#define FAULT_MAX        5
#define FAULT_WINDOW_MS  10000UL

typedef struct __attribute__((packed)) {
  uint32_t magic;
  int16_t  speed;   // -1000..1000
  uint8_t  flags;   // bit0 = horn
  uint8_t  seq;
} Packet;

typedef struct __attribute__((packed)) {  // telemetry back to the remote
  uint32_t magic;
  uint16_t packMv;
  uint8_t  seq;
} Ack;

volatile int16_t  targetSpeed = 0;
volatile uint8_t  rxFlags     = 0;
volatile uint32_t lastRxMs    = 0;
volatile uint8_t  lastSeq     = 0;
volatile bool     needAck     = false;
volatile uint8_t  remoteMac[6] = {0};
bool     peerAdded    = false;

int16_t currentSpeed  = 0;
bool    lowBatt       = false;
bool    driverAwake   = false;
bool    faultShutdown = false;

void onRecv(const esp_now_recv_info_t *info, const uint8_t *data, int len);
void driverSleep();
void driverWake();
void driveMotor(int16_t speed);
uint32_t packMv();

void onRecv(const esp_now_recv_info_t *info, const uint8_t *data, int len) {
  if (len != sizeof(Packet)) return;
  Packet p;
  memcpy(&p, data, sizeof(p));
  if (p.magic != MAGIC) return;
  targetSpeed = constrain(p.speed, (int16_t)-1000, (int16_t)1000);
  rxFlags     = p.flags;
  lastSeq     = p.seq;
  for (int i = 0; i < 6; i++) remoteMac[i] = info->src_addr[i];
  lastRxMs    = millis();     // last: only after this is the rest valid
  needAck     = true;
}

// ---------- driver on/off ----------
void driverSleep() {
  ledcWrite(PIN_IN1, 0);          // both inputs low = coast
  ledcWrite(PIN_IN2, 0);
#if HAVE_NSLEEP
  digitalWrite(PIN_NSLEEP, LOW);  // outputs high-Z, logic reset
  driverAwake = false;
#endif
}

void driverWake() {
  if (driverAwake) return;
  ledcWrite(PIN_IN1, 0);          // both inputs low first...
  ledcWrite(PIN_IN2, 0);
#if HAVE_NSLEEP
  digitalWrite(PIN_NSLEEP, HIGH); // ...only then wake it up
  delayMicroseconds(WAKE_US);
#endif
  driverAwake = true;
}

void driveMotor(int16_t speed) {
  if (!driverAwake) return;
  // PWM on one input, the other low: the bridge alternates between drive and
  // coast. That is FAST decay — more current ripple than slow decay, but it
  // works with two GPIOs and is perfectly fine on an N20 at 20 kHz.
  const int maxDuty = (1023 * MAX_DUTY) / 100;
  int duty = (int)((long)abs(speed) * maxDuty / 1000);
  if (speed > 0)      { ledcWrite(PIN_IN2, 0); ledcWrite(PIN_IN1, duty); }
  else if (speed < 0) { ledcWrite(PIN_IN1, 0); ledcWrite(PIN_IN2, duty); }
  else                { ledcWrite(PIN_IN1, 0); ledcWrite(PIN_IN2, 0);    }
}

uint32_t packMv() {
  uint32_t sum = 0;
  for (uint8_t i = 0; i < VSENSE_SAMPLES; i++) sum += analogReadMilliVolts(PIN_VSENSE);
  float pin = (float)sum / VSENSE_SAMPLES;      // voltage AT D0
  return (uint32_t)(pin * VDIV_RATIO * VDIV_CAL);
}

void setup() {
  Serial.begin(115200);

  // 1) driver hard off before anything else — the motor must not twitch at boot.
  // Without an nSLEEP wire that is not possible, but it is also not needed:
  // IN1/IN2 are high-Z at boot and the DRV8833 has internal pulldowns on them,
  // so both low = coast.
#if HAVE_NSLEEP
  pinMode(PIN_NSLEEP, OUTPUT);
  digitalWrite(PIN_NSLEEP, LOW);
  driverAwake = false;
#else
  driverAwake = true;                  // EEP is tied to VCC
#endif
#if HAVE_NFAULT
  pinMode(PIN_NFAULT, INPUT_PULLUP);   // an external 10k to 3V3 is fine, this is the backup
#endif

  pinMode(PIN_LED, OUTPUT);
  digitalWrite(PIN_LED, LOW);

  // Disable the on-board cell divider of the XIAO: on the locomotive nothing is
  // connected to the BAT pads, so that reading is meaningless and the enable
  // must not float.
  pinMode(PIN_BATSENSE_EN, OUTPUT);
  digitalWrite(PIN_BATSENSE_EN, LOW);

  // The order of ledcAttach determines channel and timer assignment:
  // IN1 and IN2 share a timer at 20 kHz, the buzzer gets its own timer.
  // Do not reorder: otherwise the horn drags the motor frequency along.
  ledcAttach(PIN_IN1, PWM_FREQ, PWM_RES);
  ledcAttach(PIN_IN2, PWM_FREQ, PWM_RES);
  ledcWrite(PIN_IN1, 0);
  ledcWrite(PIN_IN2, 0);
  ledcAttach(PIN_BUZZ, 2000, 10);
  ledcWrite(PIN_BUZZ, 0);

  analogSetPinAttenuation(PIN_VSENSE, ADC_11db);

  WiFi.mode(WIFI_STA);
  WiFi.setSleep(false);                // modem sleep off: otherwise you miss packets
  // Both ends are now a C5 and therefore dual-band. Lock explicitly to 2.4 GHz,
  // otherwise channel 1 can end up on a different band on either side and they
  // never see each other. 2.4 GHz also penetrates wood and PETG better.
  esp_wifi_set_band_mode(WIFI_BAND_MODE_2G_ONLY);
  esp_wifi_set_channel(WIFI_CHANNEL, WIFI_SECOND_CHAN_NONE);
  esp_now_init();
  esp_now_register_recv_cb(onRecv);
  // the driver stays asleep until a valid packet with the stick at neutral arrives
}

void loop() {
  static uint32_t lastLoop = 0, lastVbat = 0, blink = 0;
  static uint32_t faultSince = 0, faultWindowStart = 0;
  static uint8_t  faultLow = 0, faultCount = 0, battStrikes = 0;
  static bool     armed = false, hornOn = false;

  uint32_t now = millis();
  if (now - lastLoop < 20) return;      // 50 Hz control loop
  lastLoop = now;

  bool linkAlive = (now - lastRxMs <= FAILSAFE_MS);

  // ---------- battery check with hysteresis, every 2 s ----------
  if (now - lastVbat > 2000) {
    lastVbat = now;
    uint32_t mv = packMv();
    if (!lowBatt) {
      if (mv < LOW_BATT_TRIP_MV) { if (++battStrikes >= LOW_BATT_STRIKES) lowBatt = true; }
      else battStrikes = 0;
    } else {
      if (mv > LOW_BATT_CLEAR_MV) { lowBatt = false; battStrikes = 0; }
    }
    // CALIBRATION LINE: put a multimeter on VBAT_SW and compare with this value.
    Serial.printf("pack %lu mV (D0 %lu mV, ratio %.3f x cal %.3f) | link %d armed %d fault %d\n",
                  (unsigned long)mv,
                  (unsigned long)(mv / (VDIV_RATIO * VDIV_CAL)),
                  VDIV_RATIO, VDIV_CAL, linkAlive, armed, faultShutdown);
  }

  // ---------- nFAULT ----------
  // Only valid while the driver is awake: right after driverWake() the chip
  // needs its wake-up time and the line says nothing about the bridge state yet.
#if HAVE_NFAULT
  if (driverAwake && digitalRead(PIN_NFAULT) == LOW) {
    if (faultLow < 255) faultLow++;
  } else {
    faultLow = 0;
  }
#endif

  if (faultLow >= FAULT_DEBOUNCE && !faultShutdown) {
    faultLow     = 0;
    currentSpeed = 0;
    driveMotor(0);
    driverSleep();                       // nSLEEP low clears the fault latch
    faultSince   = now;
    if (now - faultWindowStart > FAULT_WINDOW_MS) { faultWindowStart = now; faultCount = 0; }
    if (++faultCount >= FAULT_MAX) faultShutdown = true;   // stays off until power cycle
  }

  // ---------- neutral lockout ----------
  if (!linkAlive)                 armed = false;
  else if (targetSpeed == 0)      armed = true;

  int16_t tgt = targetSpeed;
  if (!linkAlive || !armed || lowBatt || faultShutdown) tgt = 0;

  // ---------- driver awake or asleep ----------
  bool mayDrive = linkAlive && armed && !lowBatt && !faultShutdown &&
                  (now - faultSince > FAULT_RESET_MS);
  // The target must be zero during the recovery window after a fault as well.
  // Without this line the ramp counter simply keeps running with HAVE_NSLEEP=0
  // (the driver is always awake then) and after that window the locomotive jumps
  // back to the last requested speed in a single loop.
  if (!mayDrive) tgt = 0;
  if (mayDrive)                              driverWake();
  else if (driverAwake && currentSpeed == 0) driverSleep();

  // ---------- slew rate limiting ----------
  // While the driver sleeps we cannot steer anything; the ramp counter is held
  // at zero. Otherwise it would run on during a fault towards the last requested
  // speed and the locomotive would jump to full duty in one loop on recovery —
  // exactly without the ramp that protects it.
  if (!driverAwake) {
    currentSpeed = 0;
  } else {
    if      (currentSpeed < tgt) currentSpeed = min((int)tgt, currentSpeed + SLEW_PER_LOOP);
    else if (currentSpeed > tgt) currentSpeed = max((int)tgt, currentSpeed - SLEW_PER_LOOP);
  }
  driveMotor(currentSpeed);

  // ---------- headlight ----------
  // fast blink = fault · slow blink = battery low · otherwise on while driving
  uint32_t blinkMs = faultShutdown ? 100 : (lowBatt ? 300 : 0);
  if (blinkMs) {
    if (now - blink > blinkMs) { blink = now; digitalWrite(PIN_LED, !digitalRead(PIN_LED)); }
  } else {
    digitalWrite(PIN_LED, currentSpeed != 0);
  }

  // ---------- horn ----------
  // ledcWriteTone() reconfigures the timer, so only call it on a change.
  bool wantHorn = linkAlive && (rxFlags & 0x01);
  if (wantHorn != hornOn) {
    hornOn = wantHorn;
    ledcWriteTone(PIN_BUZZ, hornOn ? 660 : 0);
  }

  // ---------- telemetry back to the remote ----------
  static uint32_t lastAck = 0;
  if (needAck && now - lastAck > 100) {
    lastAck = now;
    needAck = false;
    uint8_t mac[6];
    for (int i = 0; i < 6; i++) mac[i] = remoteMac[i];
    if (!peerAdded) {
      esp_now_peer_info_t peer = {};
      memcpy(peer.peer_addr, mac, 6);
      peer.channel = WIFI_CHANNEL;
      if (esp_now_add_peer(&peer) == ESP_OK) peerAdded = true;
    }
    Ack a = { MAGIC, (uint16_t)packMv(), lastSeq };
    esp_now_send(mac, (uint8_t *)&a, sizeof(a));
  }
}

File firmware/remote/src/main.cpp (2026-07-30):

/*
 * Brio RC Locomotive — handheld remote (transmitter)             rev F (2026-07-28)
 * Board: Seeed XIAO ESP32-C5  (PlatformIO: env xiao_esp32c5, esp32 core 3.3.x)
 *
 * Power: 1S XTAR 26650 on the XIAO BAT pads.
 * Input: KY-023 joystick — Y axis = throttle (fwd/rev), push = horn.
 * Link:  ESP-NOW broadcast @ 25 Hz, MAGIC key, fixed channel, 2.4 GHz only.
 * Sleep: deep sleep after IDLE_SLEEP_MS of centered stick; wake = joystick press.
 *
 * Change versus the previous version: the BATTERY MEASUREMENT only. See the
 * "battery measurement" block below and notes 3/4 on hardware/wiring-remote.svg.
 */

#include <Arduino.h>
#include <WiFi.h>
#include <esp_now.h>
#include <esp_wifi.h>
#include <esp_sleep.h>
#include <driver/gpio.h>
#include <HWCDC.h>

// ---------- pins ----------
// Silkscreen labels instead of bare GPIO numbers: the wiring (wire list rev F)
// goes by label, and behind D0..D4 the C5 has completely different GPIOs than
// the S3.
//   D0=GPIO1  D1=GPIO0  D2=GPIO25* D3=GPIO7*  D4=GPIO23 D5=GPIO24
//   D6=GPIO11 D7=GPIO12 D8=GPIO8   D9=GPIO9   D10=GPIO10      (* = strapping)
//
// rev F: the LEDs moved from D2/D3 to D9/D10. GPIO25 and GPIO7 are strapping
// pins on the C5 (together with GPIO2, GPIO27, GPIO28). An LED with series
// resistor parks such a pin around 1.9 V at reset — exactly in the region where
// high or low is undefined. D9/D10 are ordinary GPIOs.
#define PIN_JOY_Y    D0   // GPIO1,  ADC1_CH0 <- VRy
#define PIN_JOY_SW   D1   // GPIO0,  LP-GPIO (ext1 wake) <- SW (active low, pull-up)
#define PIN_LED_LINK D9   // GPIO9  -> green LED
#define PIN_LED_BATT D10  // GPIO10 -> red LED

// ---------- battery measurement ----------
// The ESP32-C5 has exactly ONE ADC unit: ADC1, six channels, on GPIO1..GPIO6.
// There is no ADC2 — the Wi-Fi/ADC2 conflict of the S3 does not exist on this
// board. D4 is GPIO23 here and has no ADC at all, so the external divider
// R3/R4 from rev D cannot work here.
// The XIAO C5 has the divider on board: BAT+ -> load switch (GPIO26) ->
// 100k/100k -> GPIO6 (ADC1_CH5). Both pins are defined as BAT_VOLT_PIN /
// BAT_VOLT_PIN_EN in variants/XIAO_ESP32C5/pins_arduino.h.
#define PIN_VSENSE     BAT_VOLT_PIN     // GPIO6
#define PIN_VSENSE_EN  BAT_VOLT_PIN_EN  // GPIO26, HIGH = enable the divider

// Two equal 100k resistors, so 1:2. CONFIRMED, not guessed.
#define VDIV_RATIO     2.0f
// Trim factor. The two 100k are typically +-1%, so the ratio can be off by up
// to ~2% (at 4.2 V that is ~84 mV). Measure BAT+ with a multimeter, compare
// with the line printed below and set VDIV_CAL = (multimeter / printed).
// Leave at 1.000f until you have measured.
#define VDIV_CAL       1.000f
// Averaging is not a luxury here: the divider has 100k||100k = 50k source
// impedance while the SAR ADC wants to see below 10k, and GPIO6 is not on the
// header so you cannot add a capacitor. On top of that, transmitting puts
// spikes on the reading. Seeed recommends 16x averaging in their own example.
#define VSENSE_SAMPLES 16

// ---------- tuning ----------
#define WIFI_CHANNEL   1
#define MAGIC          0xB210C0DEUL   // must match loco
#define SEND_MS        40             // 25 Hz
#define DEADBAND       80             // of ±1000
#define LOW_BATT_MV    3300
#define IDLE_SLEEP_MS  (5UL * 60UL * 1000UL)

typedef struct __attribute__((packed)) {
  uint32_t magic;
  int16_t  speed;
  uint8_t  flags;
  uint8_t  seq;
} Packet;

typedef struct __attribute__((packed)) {  // telemetry ack from loco
  uint32_t magic;
  uint16_t packMv;
  uint8_t  seq;
} Ack;

const uint8_t BCAST[6] = {0xFF,0xFF,0xFF,0xFF,0xFF,0xFF};
volatile uint32_t lastAckMs  = 0;
volatile uint16_t locoPackMv = 8000;
int joyCenter = 2048;
uint8_t seq = 0;
uint32_t lastActive = 0;
bool usbBench = false;   // USB host seen at boot -> skip deep sleep

void onRecv(const esp_now_recv_info_t *info, const uint8_t *data, int len);
int16_t readThrottle();
uint32_t cellMv();

void onRecv(const esp_now_recv_info_t *info, const uint8_t *data, int len) {
  if (len != sizeof(Ack)) return;
  Ack a;
  memcpy(&a, data, sizeof(a));
  if (a.magic != MAGIC) return;
  lastAckMs  = millis();
  locoPackMv = a.packMv;
}

int16_t readThrottle() {
  long a = 0;
  for (int i = 0; i < 4; i++) a += analogRead(PIN_JOY_Y);
  a /= 4;
  long v = ((a - joyCenter) * 1000L) / 2048L;    // approx -1000..1000
  v = constrain(v, -1000L, 1000L);
  if (abs(v) < DEADBAND) v = 0;
  return (int16_t)v;
}

// Cell voltage in mV, averaged over VSENSE_SAMPLES readings.
uint32_t cellMv() {
  uint32_t sum = 0;
  for (uint8_t i = 0; i < VSENSE_SAMPLES; i++) sum += analogReadMilliVolts(PIN_VSENSE);
  float pin = (float)sum / VSENSE_SAMPLES;      // voltage AT GPIO6
  return (uint32_t)(pin * VDIV_RATIO * VDIV_CAL);
}
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

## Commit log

2026-07-30 Initial commit: RC BRIO locomotive and remote
    Firmware, wiring documentation, CAD sources and BOM for a remote-controlled
    BRIO-compatible locomotive. Both units run a Seeed XIAO ESP32-C5 linked over
    ESP-NOW.
    Contents:
    - firmware/loco (rev D) and firmware/remote (rev F), PlatformIO, pioarduino 55.03.311
    - hardware/: wiring diagrams for both units
    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
    [Remote.3dm, Remote.stp, Train.3dm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]
2026-07-30 Translate remaining XML comments in the loco wiring diagram
2026-07-30 Add print-ready STLs meshed from the STEP sources
    Nine parts, generated from cad/*.stp with FreeCAD at 0.03 mm linear and
    0.2 rad angular deviation. All meshes are watertight, free of
    self-intersections, and within 0.32% of the CAD solid volumes. Each part is
    centred in X/Y and sits on Z=0; orientation is unchanged from the CAD.
    The locomotive body is split into four printable pieces (chassis, front,
    boiler, cab) in this CAD revision, replacing the single body of earlier
    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
    [loco-boiler.stl, loco-cab.stl, loco-chassis.stl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]
2026-07-30 Confirm the driven wheel identification in stl/README
    Pulley001 is the driven wheel, confirmed against the design.
2026-07-30 Document why the body is split and how the pieces join
    The three top pieces (front, boiler, cab) exist so each prints with little or
    no support; they are glued together with superglue.
2026-07-30 Document electronics mounting, insulation and the external USB-C charge socket
    No e-shelf: the boards mount in the chassis with the boiler and cab taking the
    rest. Every board is insulated (Kapton) with no exposed conductors. Charging
    runs through a separate 2-wire USB-C socket (J2) soldered to the charge input
    of the charger board, added as L30/L31.
2026-07-30 Draw the external USB-C charge socket (J2) and L30/L31 in the loco diagram
    Canvas widened to the left so no existing element moves. The charger board's
    own USB-C port is marked unused and two charge input pads are added, with the
    socket and its two wires drawn alongside. Note 9 covers polarity and the CC
    pull-down requirement.
2026-07-30 Add rendered PNGs of both wiring diagrams
    Rendered from the SVG sources with Chrome headless at 2x scale (3580x2580 and
    2800x2040). The SVGs remain the source; hardware/README documents how to
    re-render. Both wire lists now embed their diagram.
2026-07-30 Re-render wiring diagram PNGs [skip ci]
